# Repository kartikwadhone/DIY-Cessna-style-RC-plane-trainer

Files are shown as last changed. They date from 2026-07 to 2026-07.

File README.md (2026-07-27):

# Sky Soarer
Screenshot_20260716_073851_Gallery

A very easy to build rc airplane that requires minimal effort and funds. However this project does require some knowledge of electronics and aerodynamics. :)

#  Demo

**Flight Video:** 
https://youtube.com/shorts/hdI_K4hGbNI?si=ZF_V9rFV4TuXbcLE

**Strobe Lights:**
https://www.youtube.com/shorts/_2fsilVLzS8
#  Quick Start

To build this RC plane:

1. Download the files from this repository.
2. Print only the STL files that are supposed to be printed
3. Assemble the airframe.
4. Install the electronics.
5. Balance the center of gravity.
6. Fly!

---

#  Features

- Over 15 min Flight time
- Under 800g (Depends on configuration)
- Highly Stable
- Good Vertical Climb ability

---

#  Build Guide

## 1. Print the Parts

Print all STL files using:

- Material: PETG
- Layer Height: 0.2mm
- Infill: 20%
- Supports: Organic auto generated
- Perimeters: 3
  
## 2. Assemble the Airframe

Cut and Glue the parts together.
When glueing the sides to the bottom make sure they follow this diagram:



---

## 3. Install Electronics

Install motor in motor mount and connect to the ESC. Then Plug in all 4 servos into the reciever. Lastly plug in the battery into the ESC. Make sure the ESC's BEC is connected in channel 3 to the reciever the provide power to the servos and throttle control.

---

## 4. Balance the Plane

Since this is a plane with a rectangular wing, balancing the plane is very easy. Balance the plane so that you can hold it 1/3 of the way back from the wing.

---

## 5. Pre-Flight Checklist

- Control surfaces move correctly
- Battery secured so it does not move around in flight
- Propeller tightened
- Center of gravity checked
- Radio connected

---

#  Repository Structure

```
├── README.md
├── LICENSE
├── bom.csv
├── Build Guide.pdf
│
├── Blueprints/
├── CAD/
├── Code/

```

#  Specifications

| Item | Value |
|---|---|
| Wingspan |1M |
| Length | 75cm|
| Weight | ~800g|
| Battery | 2200mah 3s Lipo|
| Flight Time | 15-20 mins|
| Motor | 2122 1200 kv 3s brushless DC motor|
| Propeller | 8x6 in|
---

#  Lessons Learned

- Chose the right battery. As batteries get bigger flights time benifits usually decline
- The center of gravity is the most importand pre flight check to do

---

#  Future Improvements

- Automatic wind stabilization
- Retractable landing gear
- Lights that can be toggled on and off

---

# Disclaimer  
This project is provided for educational and personal-use purposes only. By building, modifying, or operating this RC aircraft, you acknowledge that you are solely responsible for ensuring that your use complies with all applicable local, state, national, and international laws, regulations, and safety requirements.

In the United States, this includes complying with all applicable rules and regulations of the Federal Aviation Administration (FAA), including but not limited to registration requirements, Remote ID requirements (where applicable), airspace restrictions, and safe operating practices.

The design, files, and information in this repository are provided "as is" without any warranties or guarantees of safety, performance, or fitness for a particular purpose. I am not responsible or liable for any injuries, property damage, legal violations, financial losses, or other consequences resulting from the construction, modification, operation, or misuse of this project.

By using the files or information in this repository, you accept full responsibility for your actions and agree to operate the aircraft safely and legally.

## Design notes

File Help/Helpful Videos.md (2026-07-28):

[RC electronics for Noobs-Sam Shepard](https://www.youtube.com/watch?v=j61Q3e8AFR4)

[What KV motor is best for you?-RCMakerLab](https://www.youtube.com/watch?v=g3ZRp6UCkp0)

[Build a Foam Wing in 10 Minutes! -Tim Mckay](https://www.youtube.com/watch?v=s-btyW70FOU)

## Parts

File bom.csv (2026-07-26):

Item | Category | Quantity | Specifications | Recommended Part | Estimated Cost (USD) | Notes
Foam Board | Airframe | 3 | 20 x 30 in | Adams Ready Board | 3.75 | Main building material
Brushless Motor | Power System | 1 | 2212 1200KV | 2212 1200KV Outrunner | 15.00 | Provides Thrust
Electronic Speed Controller (ESC) | Power System | 1 | 40A | 40A Brushless ESC | 18.00 | Supports 3S battery
LiPo Battery | Power System | 1 | 3S 2200mAh 30C | XT60 Connector | 22.00 | Power source
Propeller | Power System | 1 | 8x6 | APC Style 8x6 | 3.00 | Moves air when spun
Prop Adapter | Power System | 1 | M5 | Aluminum Prop Adapter | 3.00 | May be included with motor
9g Servo | Control System | 4 | Metal Gear Recommended | MG90S | 4.00 | Ailerons, Elevator, Rudder
Servo Extension Cable | Control System | 2 | 300mm | JR Style | 2.00 | May be needed for wing servos
Pushrods | Control System | 2 | 1.2–1.5 mm Steel | Adjustable Pushrods | 4.00 | Control linkages
Control Horns | Control System | 3 | Plastic | Nylon Horn Set | 3.00 | Elevator, Rudder, Ailerons
Receiver | Radio System | 1 | Compatible with transmitter | FlySky Receiver | 18.00 | Depends on radio
Transmitter | Radio System | 1 | 6+ Channels | FlySky FS-i6X | 60.00 | Required unless already owned
M3 Screws | Hardware | 10 | Various lengths | Steel Socket Head | 3.00 | Motor mount and assembly
M3 Lock Nuts | Hardware | 10 | Nylon Insert | Steel | 2.00 | Prevent loosening
Velcro Battery Strap | Hardware | 2 | 20 × 300 mm | Hook-and-Loop Strap | 4.00 | Secure battery
Hook-and-Loop Tape | Hardware | 1 | Adhesive Backed | Industrial Velcro | 5.00 | Mount battery and receiver
Heat Shrink Tubing | Electrical | 1 | Assorted Sizes | Heat Shrink Kit | 6.00 | Wire protection
XT60 Connectors | Electrical | 2 | Male/Female Pair | Amass XT60 | 3.00 | Battery connectors
18AWG Silicone Wire | Electrical | 1 | 1 m Red/Black | High Strand Count | 4.00 | Power wiring
Hot Glue Sticks | Consumables | 20 | Mini or Standard | High Temp | 5.00 | Assembly
Packing Tape | Consumables | 1 | Clear, Heavy Duty | Packing Tape | 3.00 | Reinforcement
Duct Tape | Consumables | 1 | Optional | Duct or Vinyl Tape | 5.00 | Orientation and decoration
Y Servo Harness | Control System | 1 | 1 Male to 2 Female JR Servo Splitter | Standard Y-Harness | 3.00 | Used to connect two servos to one receiver channel
Servo Extension Cable | Control System | 2 | 200 mm JR Extension | JR Servo Extension | 2.00 | Extends servo wires for wing-mounted servos
200 Ω Resistor | Electronics | 6 | 200 Ω, 1/4 W, ±5% | Carbon Film Resistor | 0.10 | Current limiting resistor for RGB LEDs
Arduino Nano | Electronics | 1 | ATmega328P, USB Mini-B | Arduino Nano V3 Compatible | 8.00 | Microcontroller for lighting
RGB LED | Electronics | 6 | 5 mm Common Cathode RGB LED | Diffused RGB LED | 0.50 | Navigation lights
26 AWG Wire | Electronics | 4 | 26 AWG, Silicone Insulated, Roll | 26 AWG Silicone Wire | 5.00 | General-purpose wiring for electronics

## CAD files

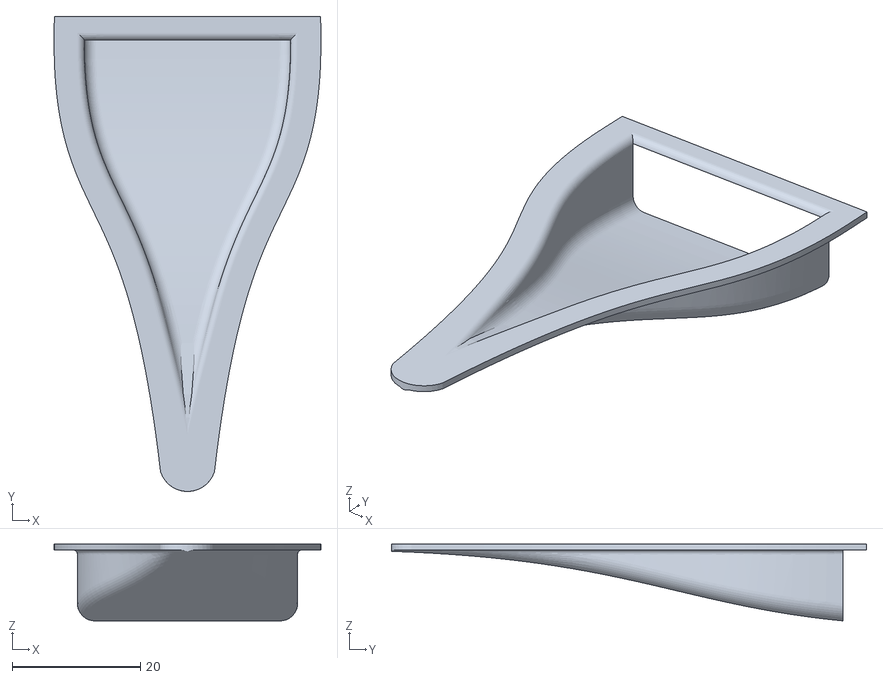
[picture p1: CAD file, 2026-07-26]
CAD Files/Naca duct to scale.stl
41.7 x 74.2 x 12.0

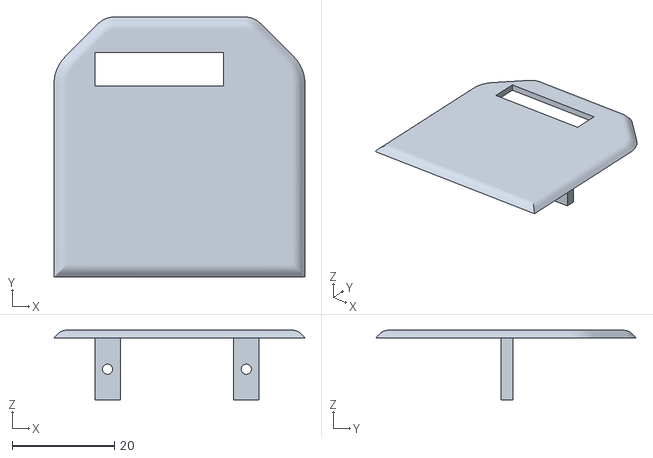
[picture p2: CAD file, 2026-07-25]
CAD Files/Servo Mount.stl
49.2 x 51.0 x 13.6

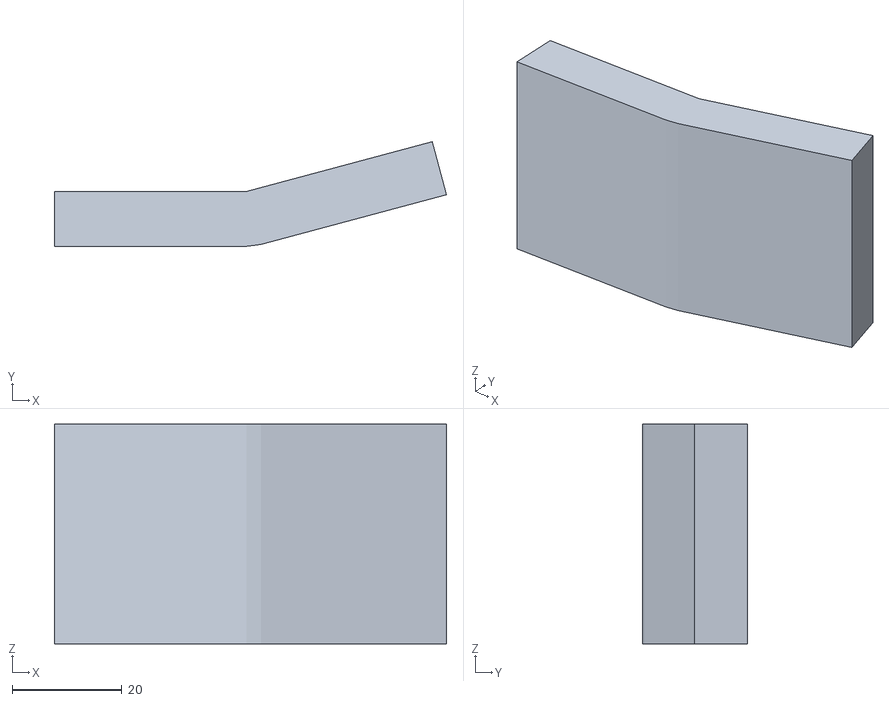
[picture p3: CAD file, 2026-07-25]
CAD Files/15 degree dihedral.stl
71.4 x 19.1 x 40.0

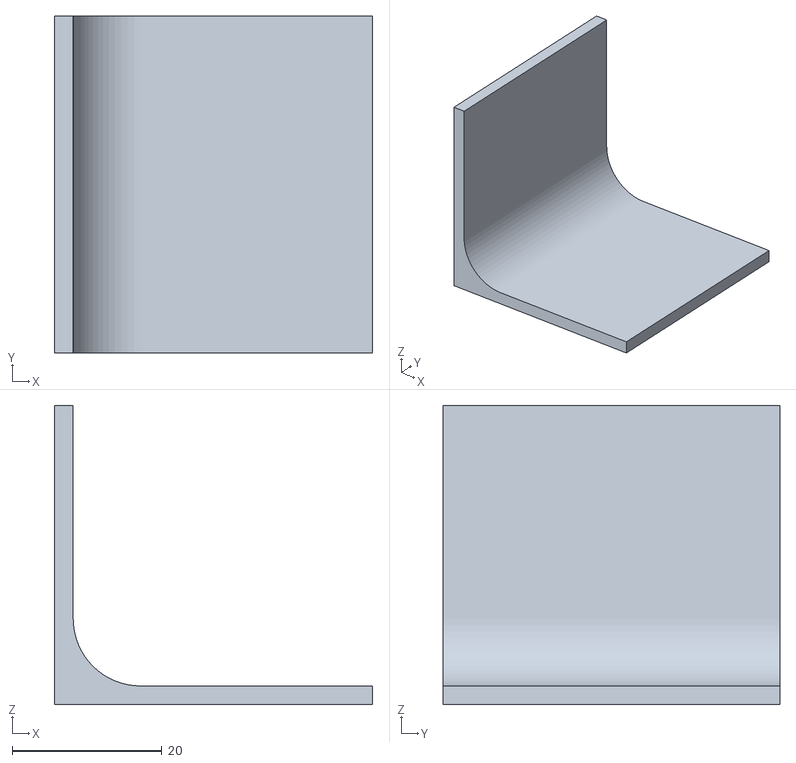
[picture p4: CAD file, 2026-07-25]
CAD Files/Rudder and elevator brace.stl
42.5 x 45.0 x 40.0

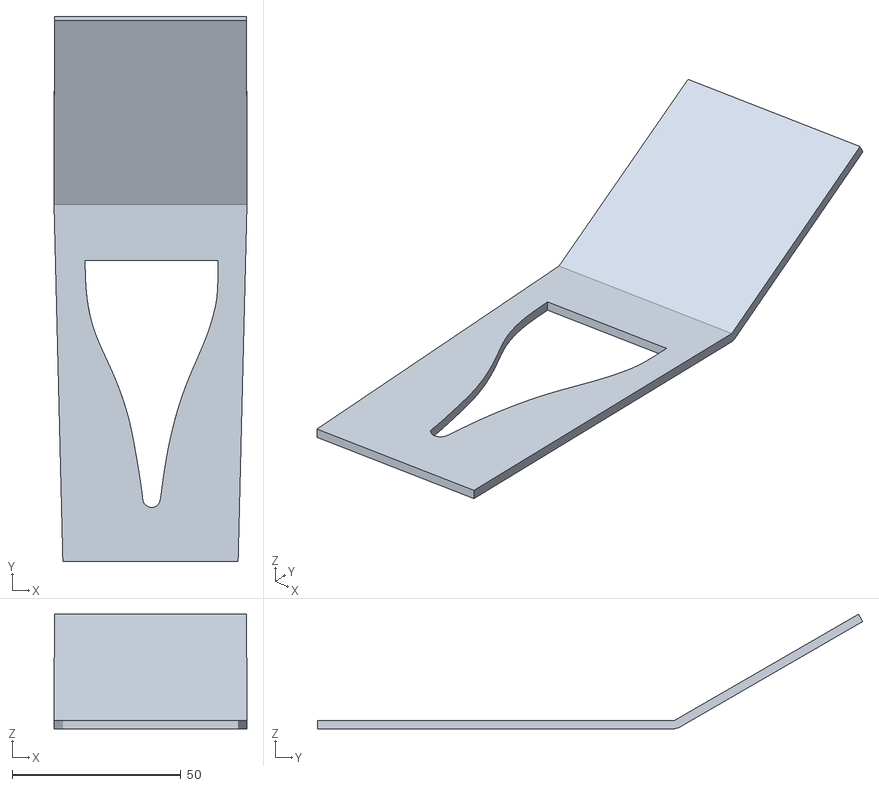
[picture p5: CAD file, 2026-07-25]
CAD Files/Front panel.stl
57.2 x 161.8 x 34.0

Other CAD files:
CAD Files/.STL

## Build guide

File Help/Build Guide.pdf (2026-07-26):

## All Dimensions are in centimeters(CM) Step 1: Fuselage

Firstly you need to assemble the airframe. Cut out all the parts from the blueprints section of the github repository. It is best to cut out the 2 sides and the bottom piece first. After cutting, glue them so that the two sides sandwich the bottom in between them. Make sure you do not put the sides on top of the bottom piece.

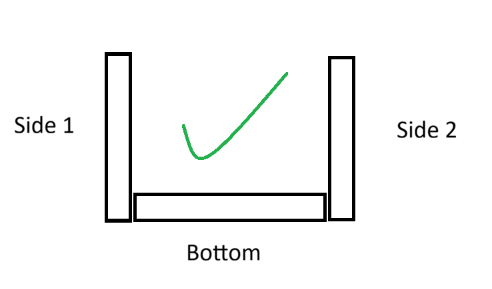
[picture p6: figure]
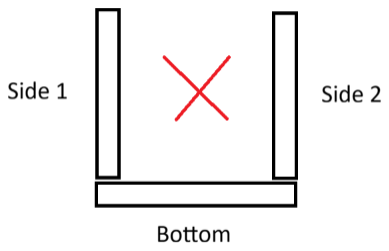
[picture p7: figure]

## Step 2: Wing

Next cut out the “wing” pieces. Both halves require the same size piece of foam. Also cut out 2 “wing spars” for each wing half and glue both spars together. Once the two spars are glued together, set it aside and peel the paper off the 22.3 x 50 cm area off both wing halves. If the paper is not peeling off properly, try to use 91% isopropyl alcohol to dissolve the glue.

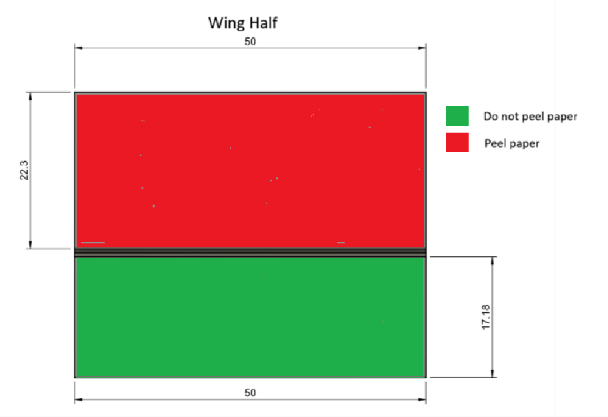
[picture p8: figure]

Next place and glue the wing spar onto the highlighted area. It is one inch back from the crease in the non-peeled area.

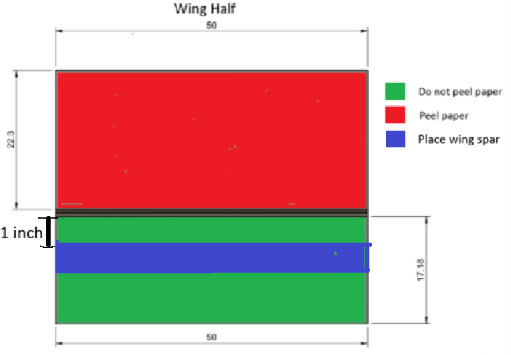
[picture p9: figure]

This next part is an optional aesthetic upgrade to add strobe lights to your place. Note: It does not significantly affect the plane’s stability, responsiveness and aerodynamic efficiency.
Skip to Page 5 if you wish to not install any lights.

You need 1 programmable board that is compatible with arduino IDE (An arduino nano is recommended for the most lightweight lights system) , 6 5v RGB leds, 6 200 ohm resistors and 4 rolls of differently colored 26 AWG wire(Red, Black, Green and Blue). Run red, blue, green an black wires to the tail of the plane and solder them. Black wire the GND, Red wire to pin 2, Green wire to pin 3, Blue wire to pin 4. Now solder other ends of the wire to the leds and make sure the colors match. Black always goes to the cathode(The longest leg) via a 200 ohm resistor.

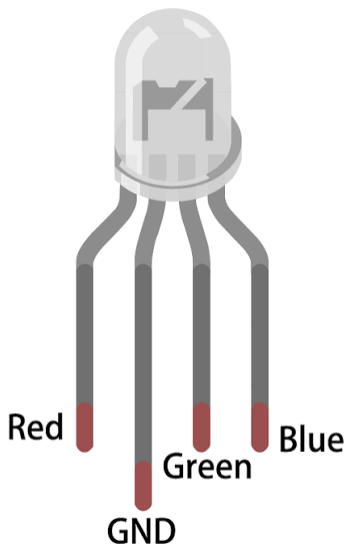
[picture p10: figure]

Next run a red and black wire through the wing and solder 2 leds to the wire. Black to GND and red to red on led and pin 4 on arduino. Repeat with a black and green wire on the right side.

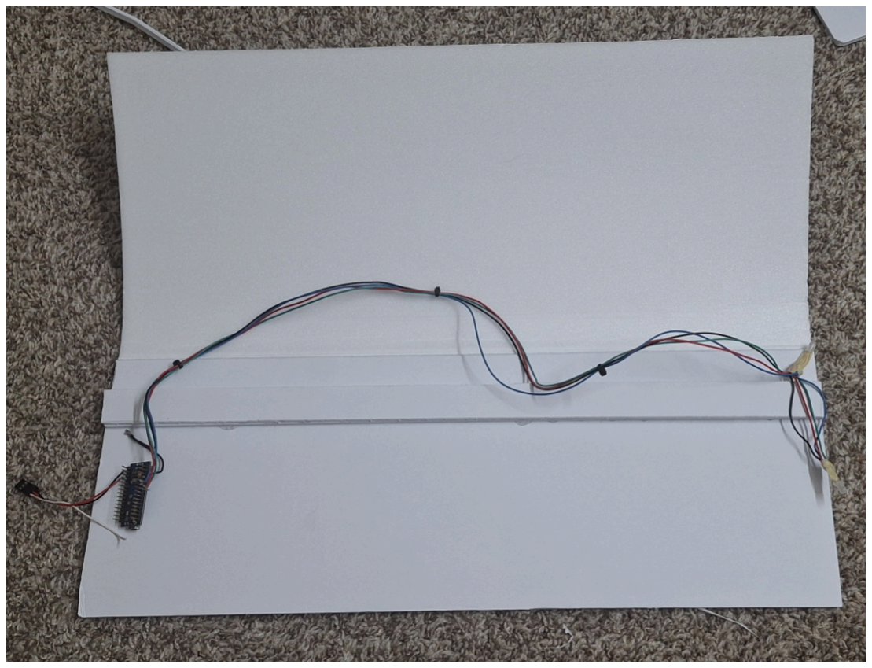
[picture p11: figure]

Note:Aircraft navigation lights use a standard color code and placement: a red light on the left wingtip, a green light on the right wingtip, and a white light on the tail
Finally connect a 3 pin connector (like the ones found on your servos) and cut off the signal wire. Connect the red wire to arduino 5v and the black wire the arduino’s second GND pin.

## Step 2: Wing (Continued)

Now install the servo mount into the bottom of the wing by printing the “servo mount.stl” and using the 2 screws that were included in the packet to install the servo. Next cut a hole in the bottom of the wing and slot in the servo mount and glue it in place. Next attach the pushrod in place.

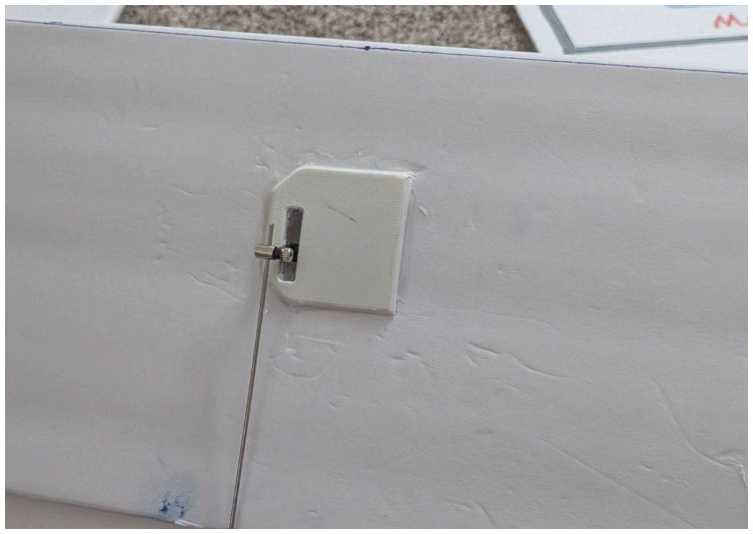
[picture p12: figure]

Now crease the line when the peeled and non-peeled section meet and fold the peeled section over the wing spar and non peeled area like in this video:
Wing Building Demo (https://drive.google.com/file/d/186-QysFpDNG1n4PijHVnwWerTL-a6z7_/view?usp=sharing)
Make sure you apply hot glue to the top of the wing spar prior to this.
Repeat with the right side as well but make sure the flat part of both the servo mount faces the fuselage. If the servos move together the plane will not roll. They should be placed in opposite orientations so that when they are connected with a y cable to a single channel on the receiver one goes up the other goes down.

After constructing the other half, route all the wires out of each wing half so that they all come out of the bottom of where the two halves meet. Next 3d print the “15 degree dihedral.stl” as the connecting piece between the wing halves and glue it in place.

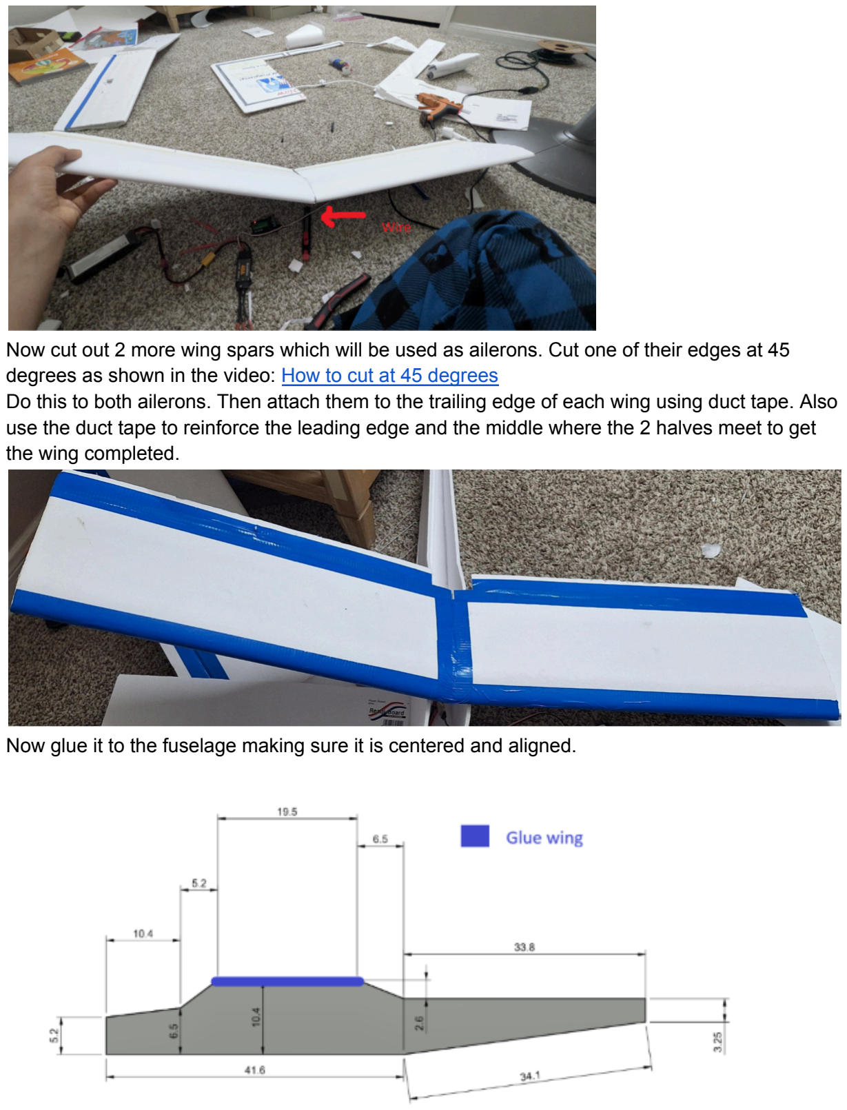
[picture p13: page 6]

Now cut out 2 more wing spars which will be used as ailerons. Cut one of their edges at 45 degrees as shown in the video: How to cut at 45 degrees (https://drive.google.com/file/d/1eP1uo7jw2DjtPlnCUjx-4b6r5qlUPucD/view?usp=sharing)
Do this to both ailerons. Then attach them to the trailing edge of each wing using duct tape. Also use the duct tape to reinforce the leading edge and the middle where the 2 halves meet to get the wing completed.

Now glue it to the fuselage making sure it is centered and aligned.

## Step 3: Tail

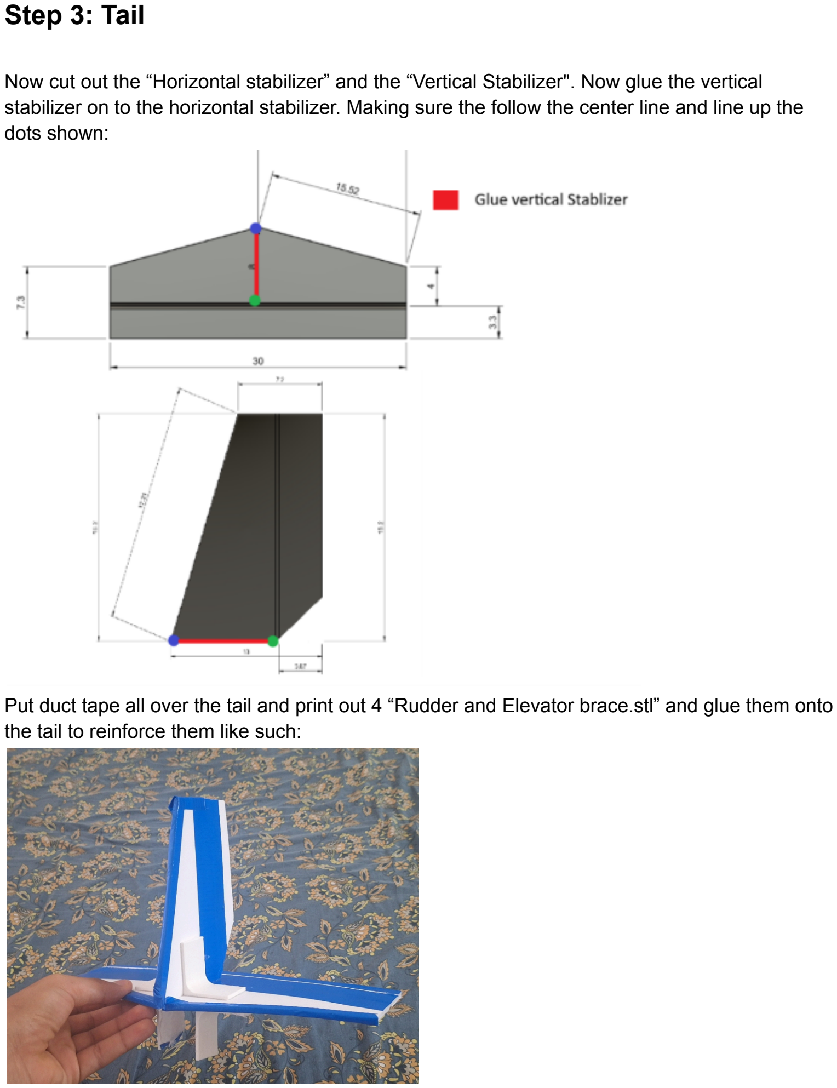
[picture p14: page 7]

Now cut out the “Horizontal stabilizer” and the “Vertical Stabilizer". Now glue the vertical stabilizer on to the horizontal stabilizer. Making sure the follow the center line and line up the dots shown:

Put duct tape all over the tail and print out 4 “Rudder and Elevator brace.stl” and glue them onto the tail to reinforce them like such:

Finally glue the tail onto the end of the fuselage and connect your last servo to the elevator/horizontal stabilizer to complete the airframe!

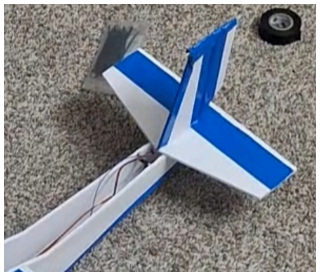
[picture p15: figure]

## Step 4: Electronics

print the “motor mount.stl” and attach your 2122 motor to it using 3 m3 nuts and screws. Connect all 3 wires into your ESC and make sure it is spinning the correct way. If it is spinning in the wrong direction, swap any 2 wires and it will reverse. Once again, the ESC 3 pin connector goes to channel 3 on the receiver.

The Y harness splitting the signal to the 2 servos in the wing goes into channel 1 in the receiver and the elevator/horizontal stabilizer servo goes into channel 2. Also if you did choose to add lights, connect the 3 pin connector coming from the arduino into any available channel except for channel 1-4. Connect your 2200 mah 3s lipo to the esc and secure it with velcro or tape to make sure it does not side during flight.

## Step 5: Balancing the plane

Balancing the plane is the single most important thing to ensure the plane flies well or even flies at all. Hold the plane on fingers and slide the battery back and forth so that it balances perfectly ⅓ the way back from the leading edge.

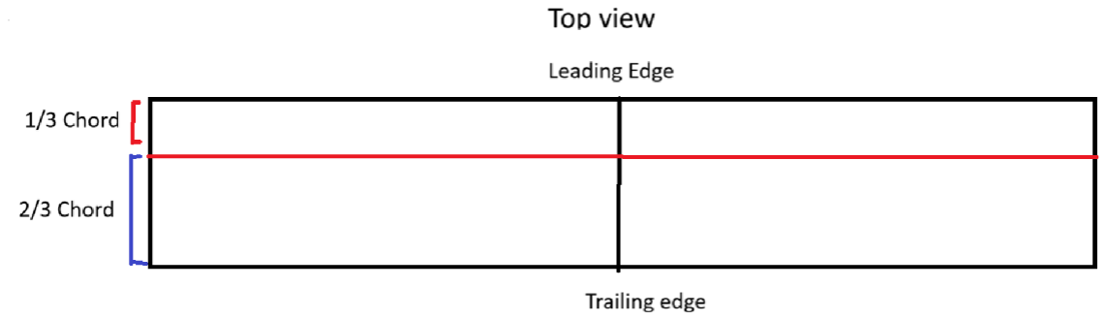
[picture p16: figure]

## Step 6: Miscellaneous

You are almost ready to fly! Just print out the “front panel.stl” and the “NACA duct to scale.stl” glue them together and secure it to the front of the plane to cover the electronics bay. It is best to use rubber bands to secure it. Put the same duct tape used previously on the bottom of the fuselage to waterproof it and help with belly landings.

## Step 7: Pre-Flight Checks

Your plane is now ready to fly! Just perform these checks to make sure your plane flies well.
- Make sure the battery is secure so it does not slide around.
- Tighten the propeller. If it falls off in flight, the plane is doomed :)
- Check all control surfaces and make sure they are moving
- Make sure the battery is charged
- Place the antenna of the receiver outside the plane to ensure good signal.

## Flight Tips

- When taking off, set the motor to 100 percent to gain airspeed fast
- Throw it at a shallow angle to avoid a stall
- Get used to the controls in a simulator before you fly the plane.

## Flight Videos

- Landing Video (https://drive.google.com/file/d/1PEo1tgmsBIEkBDuf_WXVZhxFUeS2SnHv/view?usp=sharing)
- Take Off Video (https://drive.google.com/file/d/1J0UrCdWPPQBmeuhWIvCj3K7Hajs9zt1E/view?usp=sharing)

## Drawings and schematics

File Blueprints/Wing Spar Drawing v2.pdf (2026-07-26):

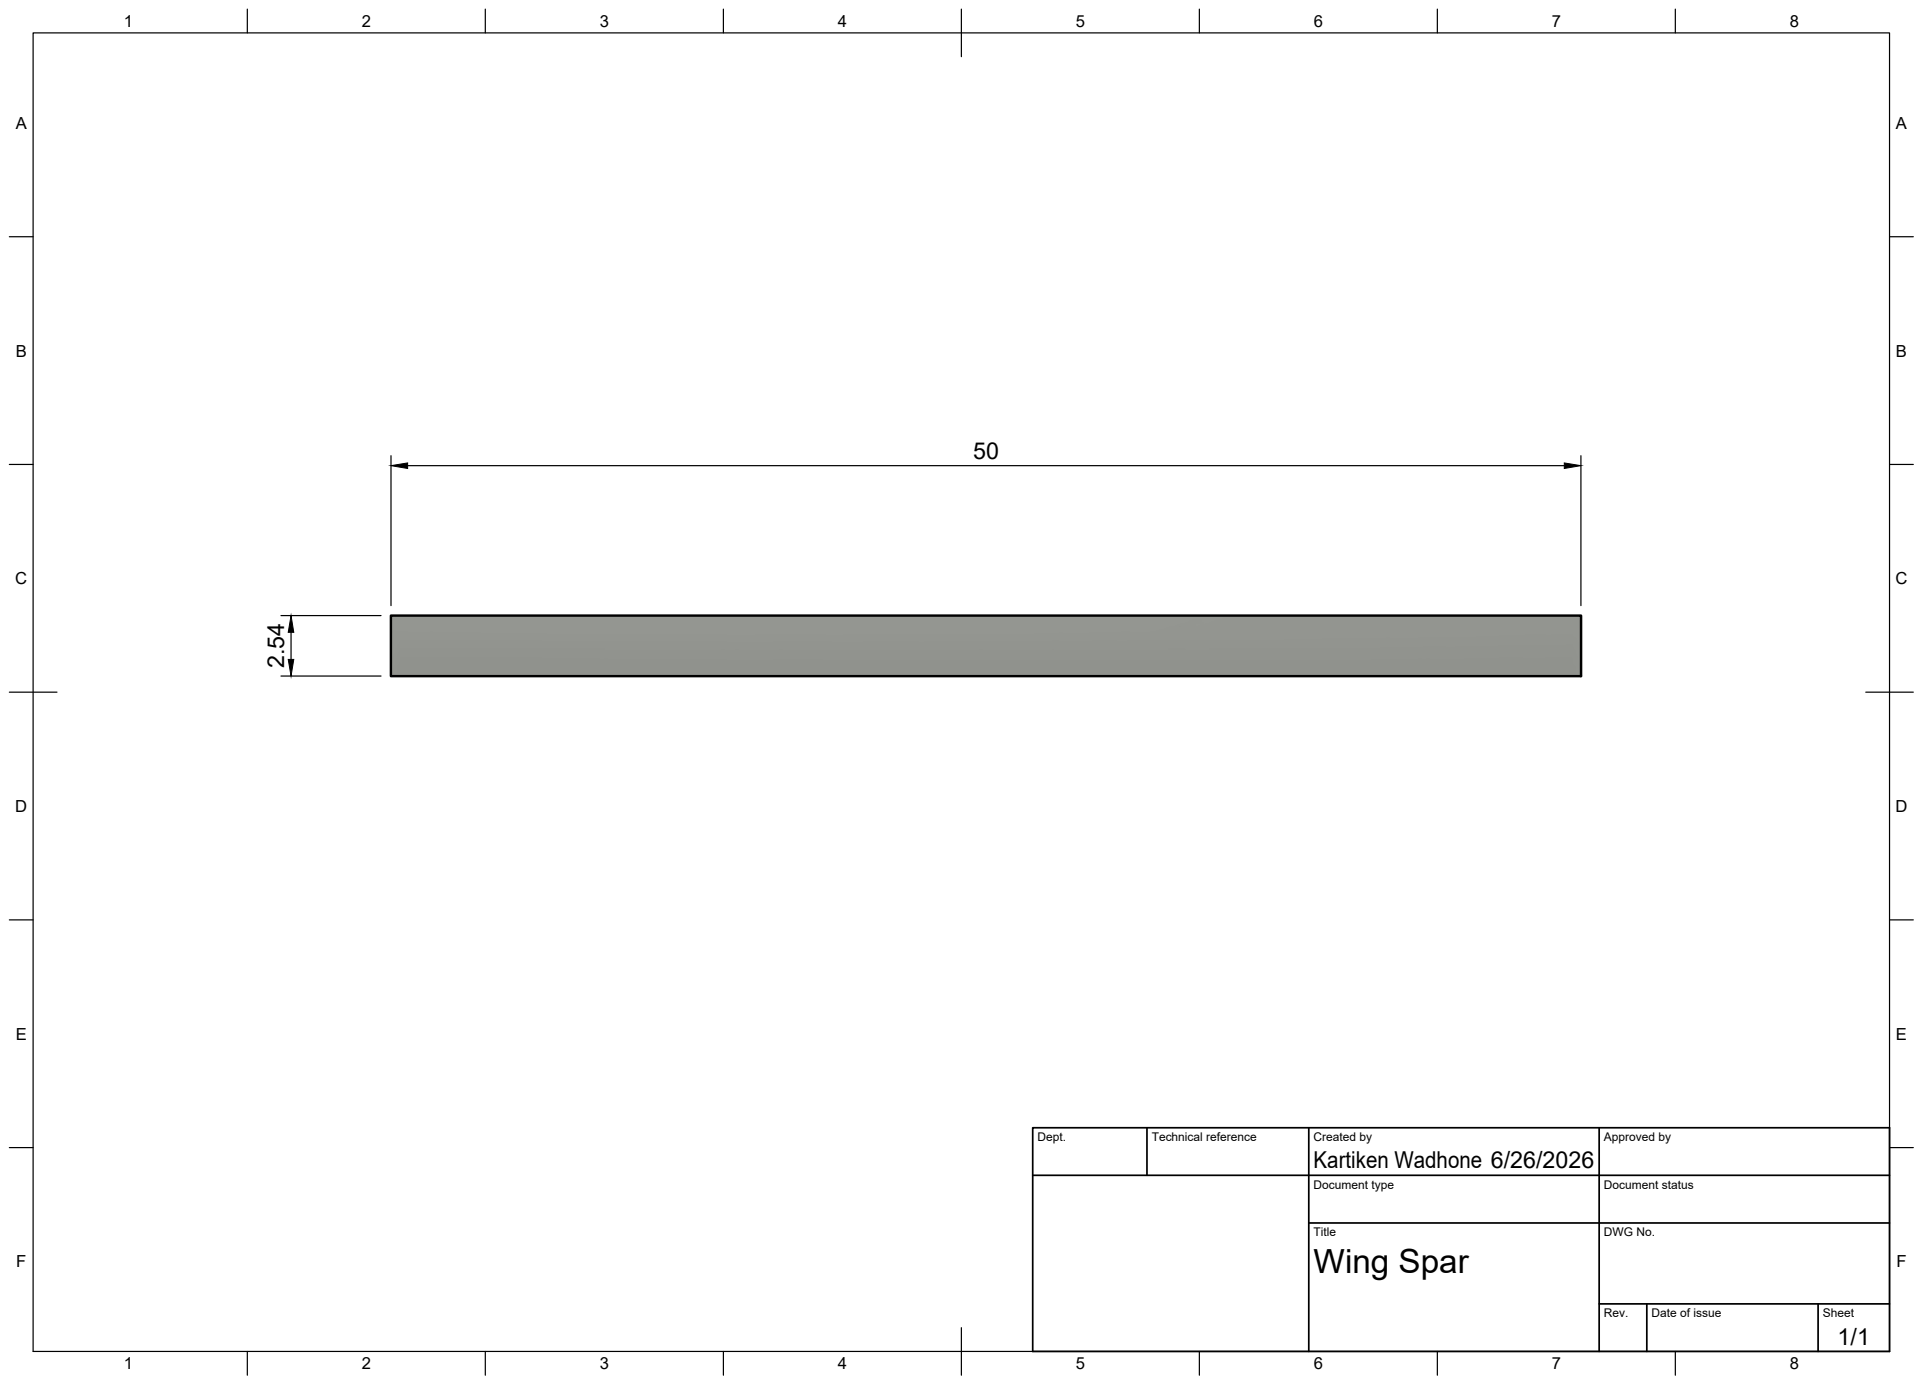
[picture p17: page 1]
Title; DWG No.; Rev.; Date of issue; Sheet; Wing Spar; Kartiken Wadhone 2.54

Dept. | Technical reference | Created by 6/26/2026 | Approved by

Document type | Document status

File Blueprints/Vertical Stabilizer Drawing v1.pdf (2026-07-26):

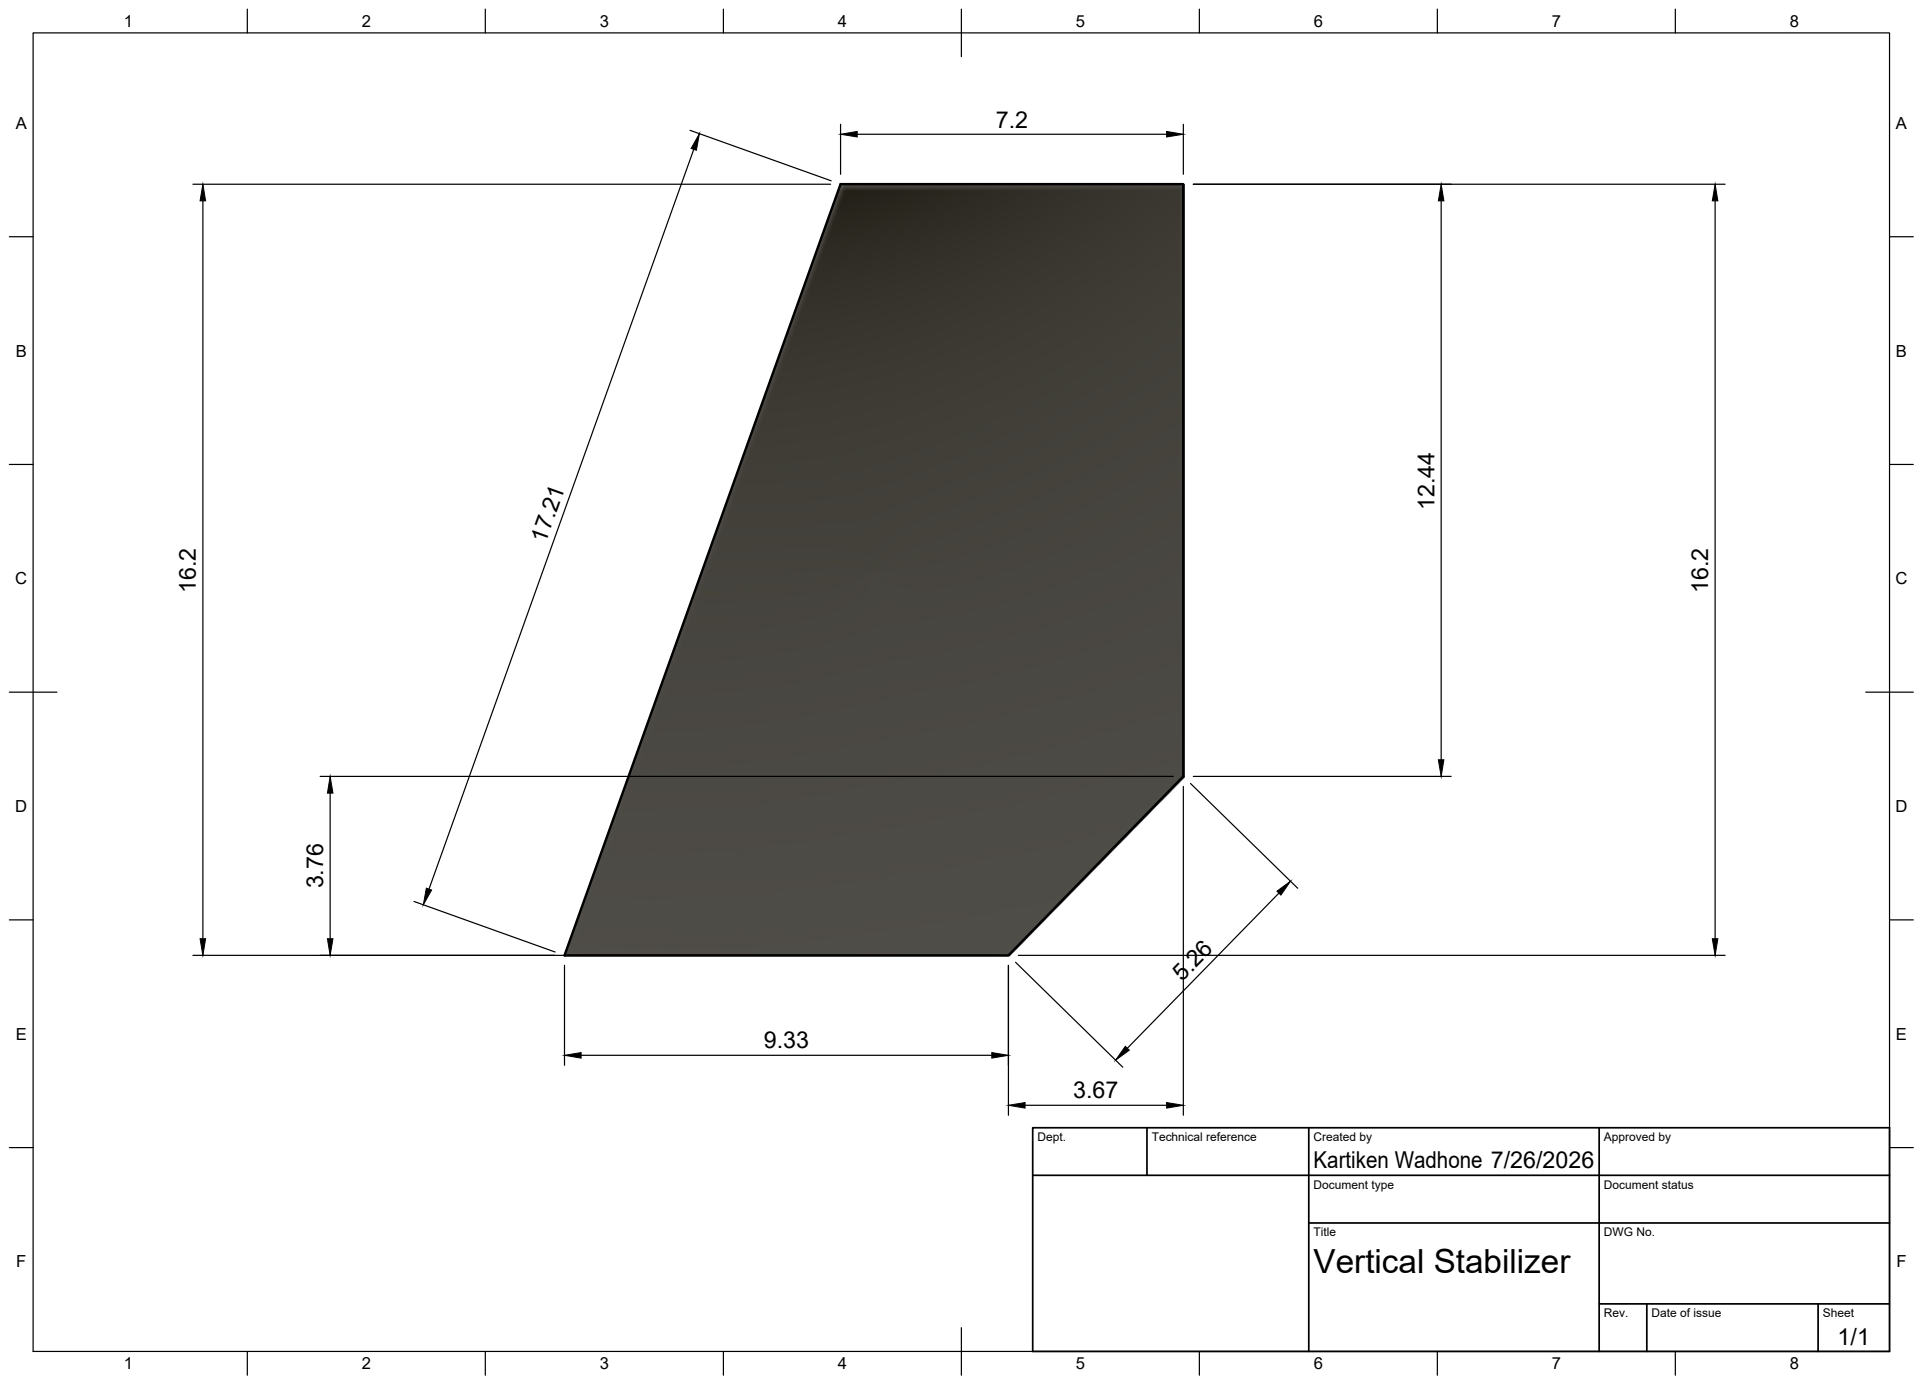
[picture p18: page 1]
Title; DWG No.; Rev.; Date of issue; Sheet; Vertical Stabilizer

Dept. | Technical reference | Created by Kartiken Wadhone 7/26/2026 | Approved by

Document type | Document status

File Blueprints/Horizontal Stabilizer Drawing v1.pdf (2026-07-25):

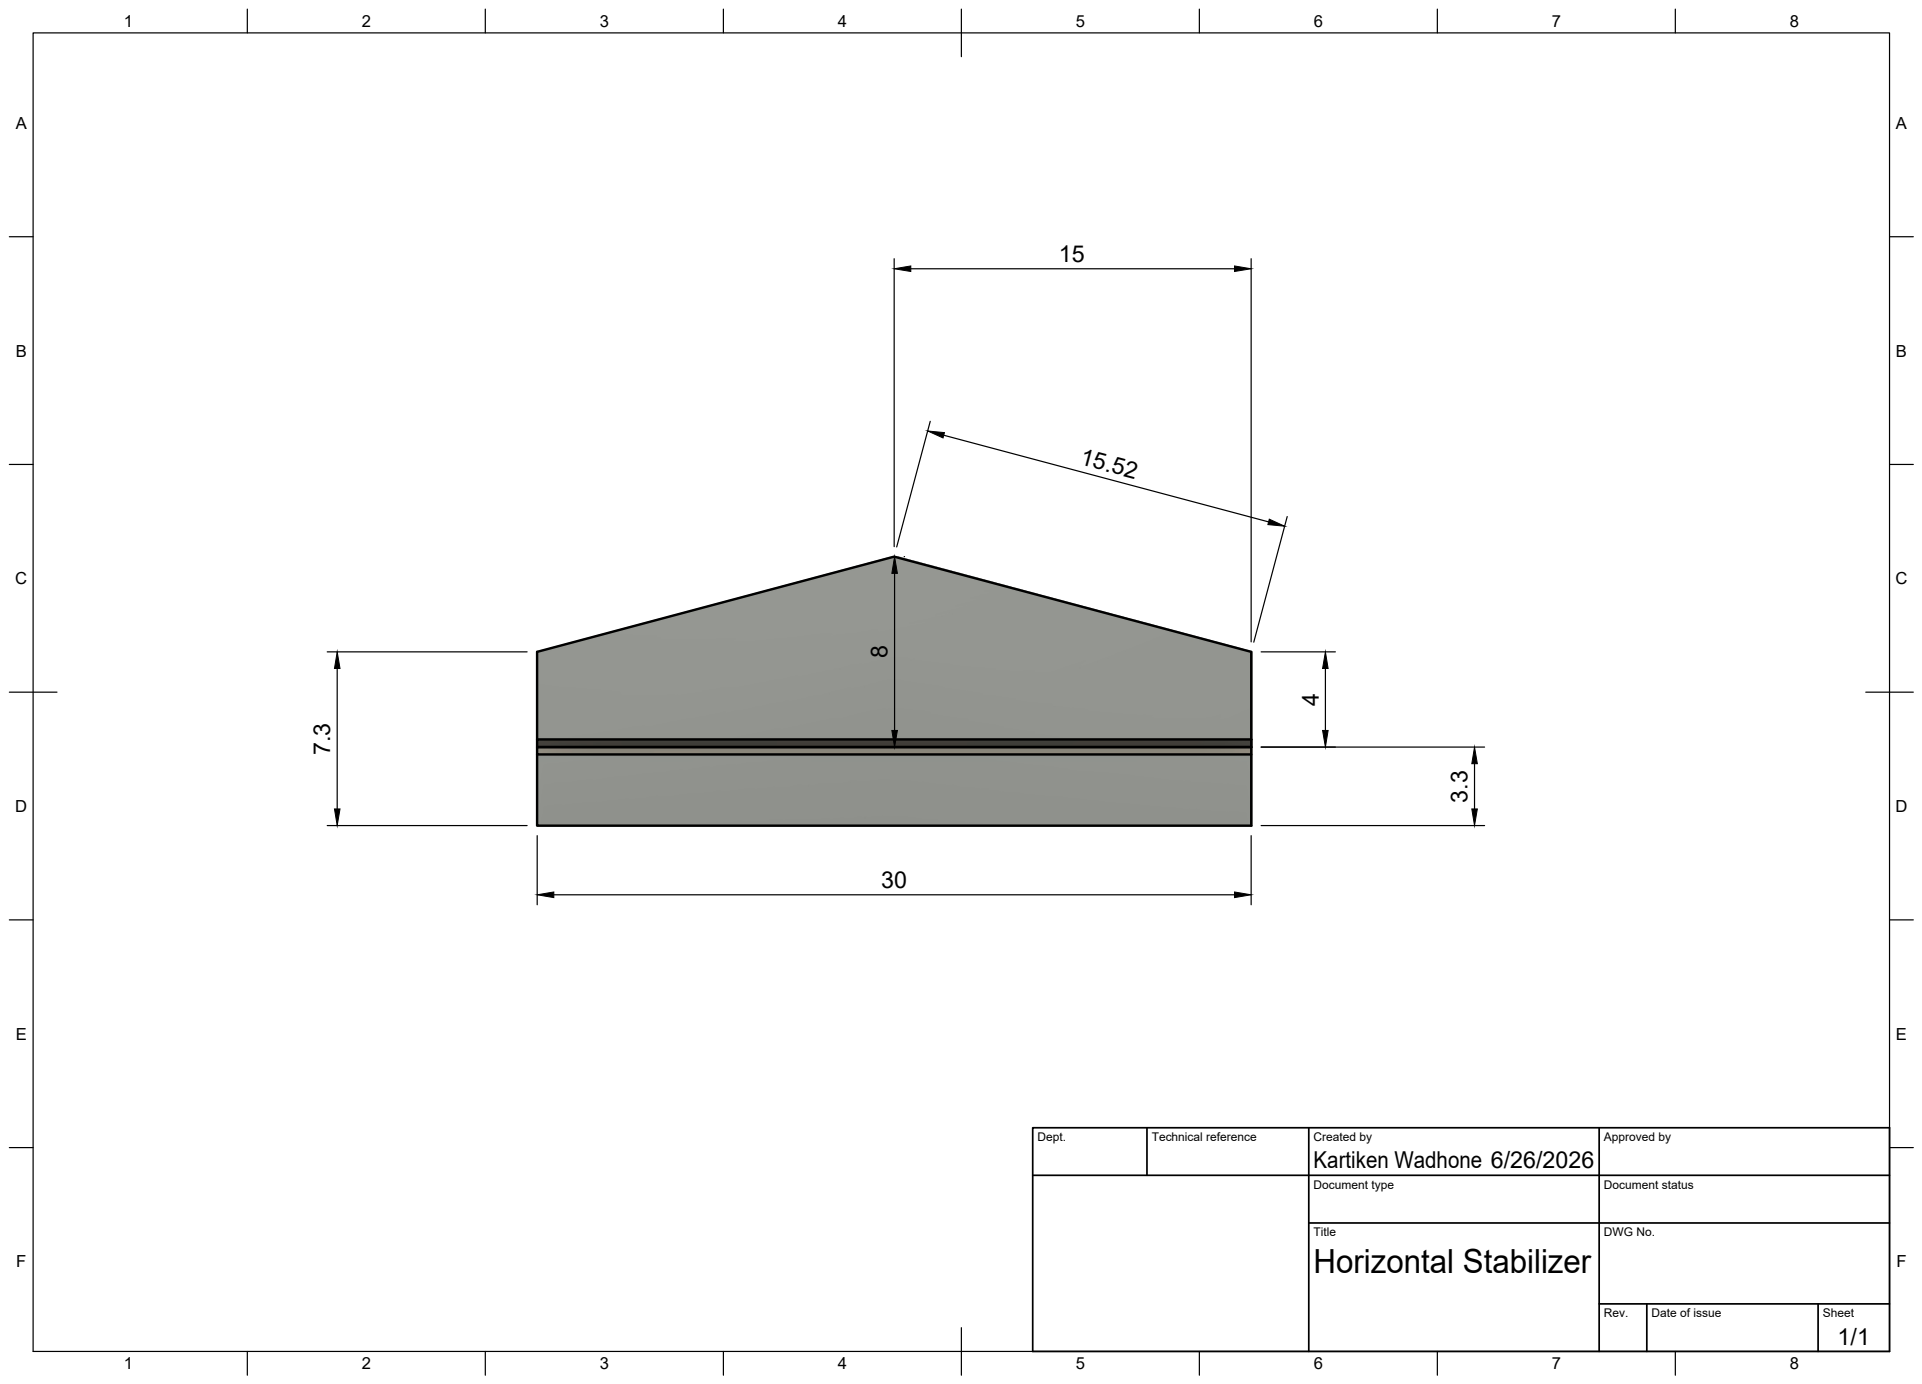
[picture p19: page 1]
Title; DWG No.; Rev.; Date of issue; Sheet; Horizontal Stabilizer; Kartiken Wadhone3.3

Dept. | Technical reference | Created by 6/26/2026 | Approved by

Document type | Document status

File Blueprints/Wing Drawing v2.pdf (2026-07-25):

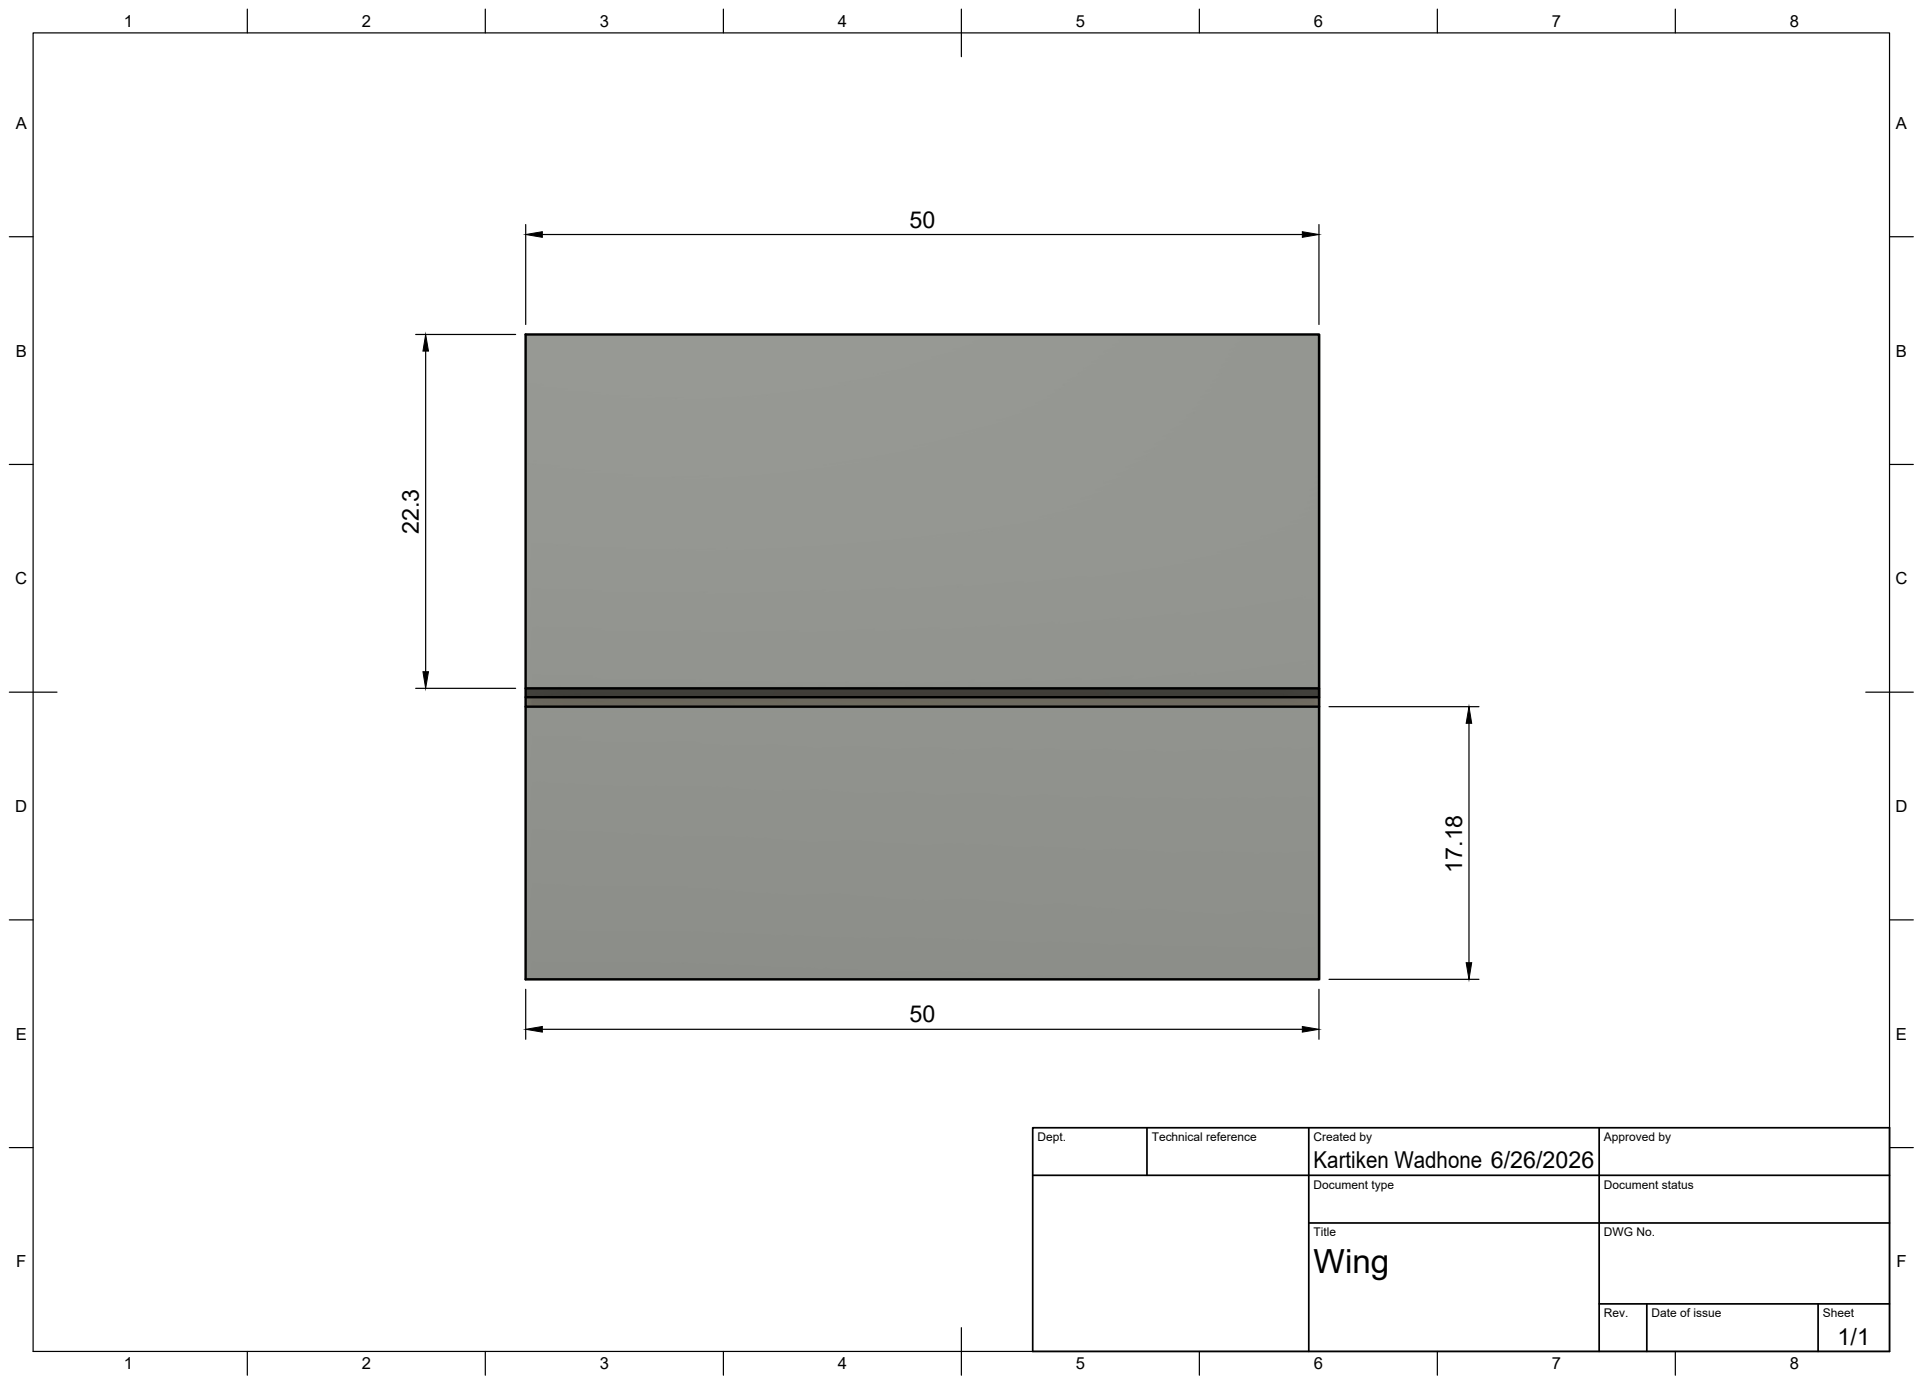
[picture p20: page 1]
Title; DWG No.; Rev.; Date of issue; Sheet; Kartiken Wadhone17.18

Dept. | Technical reference | Created by 6/26/2026 | Approved by

Document type | Document status

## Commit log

2026-07-25 Create Motor Mount
2026-07-25 Include assembly diagrams in README
    Added diagrams for assembly instructions.
2026-07-25 Fix formatting in README.md
    Removed unnecessary line break before the 'Assemble the Airframe' section.
2026-07-25 Add Bill of Materials (BOM) for project
    [BOM.csv]
2026-07-25 Update and rename BOM.csv to bom.csv
    [BOM.csv, bom.csv]
2026-07-25 Modify bom.csv with updated parts and descriptions
    Updated item details for Brushless Motor, LiPo Battery, Propeller, and removed CA Glue.
    [bom.csv]
2026-07-26 Create Strobe lights code for arduino
2026-07-26 Modify entries in bom.csv for electronics components
    Updated descriptions for Arduino Nano and RGB LED. Changed the name of 26 AWG Hook-Up Wire to 26 AWG Wire.
    [bom.csv]
2026-07-28 Add video link for KV motor selection
2026-07-28 Add new video link for building a foam wing
